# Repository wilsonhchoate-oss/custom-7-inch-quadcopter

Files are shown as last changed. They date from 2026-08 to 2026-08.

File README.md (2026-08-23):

# Custom 7-Inch Quadcopter

> A custom drone I designed, built, and got flying—learning CAD, 3D printing, electronics, and flight control along the way.

<p align="center">
  Completed Custom 7-Inch Quadcopter
</p>

<p align="center">
  <b>Mechanical Design</b> · <b>Additive Manufacturing</b> · <b>Electronics Integration</b> · <b>Flight Controls</b> · <b>Testing & Troubleshooting</b>
</p>

## Flight Demonstration

The custom quadcopter successfully achieved takeoff, stable hover, and controlled flight after iterative mechanical and software refinement.

<p align="center">
  <a href="https://youtube.com/shorts/He_OBPB06JE" target="_blank">
    Flight test video
  </a>
</p>

**[Watch the flight test →](https://youtube.com/shorts/He_OBPB06JE)** This demonstrates stable hover and controlled flight. Full test details in [Testing and Validation](docs/TESTING.md).

## Project Overview

I wanted to learn everything end-to-end. So instead of buying a kit, I designed the frame in Fusion 360, printed it in PETG, integrated all the electronics and motors, and got it flying. It's been a really fun way to learn about how all these systems actually work—from CAD design to 3D printing to flight control.

### Final Result

- **Flight status:** Successful takeoff, hover, and controlled flight
- **Final mass:** Approximately **756 g**
- **Configuration:** Custom X-configuration quadcopter
- **Propellers:** 7-inch, two-blade
- **Battery:** 3S 2200 mAh LiPo
- **Flight software:** Betaflight 4.5.3
- **Airframe material:** PETG
- **CAD platform:** Autodesk Fusion 360

## Why I Built It

Honestly, I just wanted to build a drone and understand how everything works. I wanted to learn how all the parts—motors, controllers, propellers, radio—actually work together as a system. And yeah, I wanted to actually fly something I built myself. Beyond that, I also wanted to create a custom frame that I could iterate on and improve over time. Every drone project teaches me something new, and I can take those lessons and build better versions. That's what excites me about engineering—the continuous improvement cycle and the hands-on learning that comes with it.

## Engineering Development Process

```text
Requirements
      ↓
Component Selection
      ↓
CAD Design (Fusion 360)
      ↓
3D Printing (PETG)
      ↓
Mechanical Assembly
      ↓
Electronics Integration
      ↓
Betaflight Configuration
      ↓
Subsystem Testing
      ↓
Flight Testing
      ↓
Successful Hover
```

## Engineering Highlights

### Mechanical Design

- Designed a modular frame with replaceable arms and separate top and bottom plates.
- Sized the center structure around the flight-controller and ESC stack.
- Incorporated motor mounting, wire routing, fastener access, and structural thickness constraints.
- Used PETG to balance impact resistance, printability, mass, and cost.
- Iterated arm and plate geometry to improve fit, stiffness, and assembly.

### Electronics Integration

- Integrated a 4-in-1 ESC and F405 flight controller.
- Connected A2212 1000KV brushless motors.
- Wired and configured a FlySky receiver using iBUS.
- Used an OVONIC 3S 2200 mAh LiPo battery.
- Resoldered and insulated connections after identifying reliability concerns.
- Verified motor order and direction before installing propellers.

### Flight Controls & Configuration

- Configured Betaflight 4.5.3.
- Calibrated the accelerometer on a level surface.
- Corrected flight-controller orientation and verified the 3D model response.
- Configured receiver endpoints, channel mapping, and an arm switch.
- Verified commanded motor direction against the Betaflight motor diagram.
- Diagnosed apparent throttle increases as flight-controller stabilization response during restrained or unstable testing.

### Testing & Troubleshooting

The project included several failures before successful flight. These failures became the most valuable engineering portion of the build.

| Issue | Investigation | Resolution / Lesson |
|---|---|---|
| Vehicle flipped during takeoff | Checked motor order, motor direction, propeller orientation, board alignment, and accelerometer calibration | Corrected configuration and verified every propulsion channel individually |
| Betaflight model moved incorrectly | Compared physical roll, pitch, and yaw motion with the setup model | Adjusted board orientation and recalibrated |
| Receiver setup problems | Checked wiring, protocol, channel mapping, and endpoints | Used iBUS wiring and configured usable channel ranges |
| Motor speed appeared to increase without throttle input | Evaluated behavior with props removed and during attitude disturbances | Recognized stabilization behavior and avoided unsafe restrained testing with props |
| Suspected unreliable electrical joints | Inspected, resoldered, and insulated connections | Improved electrical reliability and assembly quality |
| Initial flight instability and drift | Rechecked calibration and practiced small control inputs | Achieved flight; future work includes tuning and pilot practice |

## System Specifications

| Subsystem | Component / Value |
|---|---|
| Flight controller | F405-based controller |
| Firmware | Betaflight 4.5.3 |
| ESC | 45 A 4-in-1 ESC |
| Motors | A2212 1000KV brushless outrunners |
| Propellers | 7-inch two-blade |
| Battery | OVONIC 3S, 2200 mAh, 25C |
| Radio transmitter | FlySky FS-i6 |
| Receiver | FlySky receiver using iBUS |
| Frame | Custom Fusion 360 design |
| Frame material | PETG |
| Final vehicle mass | ~756 g |

## Repository Navigation

```text
custom-7-inch-quadcopter/
├── README.md                  # Project overview and recruiter-facing summary
├── docs/
│   ├── DESIGN.md              # Requirements, CAD decisions, and manufacturing
│   ├── ELECTRONICS.md         # Wiring and component integration
│   ├── TESTING.md             # Test plan, failures, and flight validation
│   └── LESSONS_LEARNED.md     # Engineering reflection
├── media/
│   ├── images/                # Build, CAD, wiring, and flight photos
│   └── videos/                # Hover and flight clips
├── cad/                       # CAD renders, drawings, and exported STEP/STL files
├── config/                    # Betaflight backup and settings notes
├── test-data/                 # Mass, motor, battery, or flight-test records
├── BOM.csv                    # Bill of materials
└── .gitignore
```

## Design Process

<p align="center">
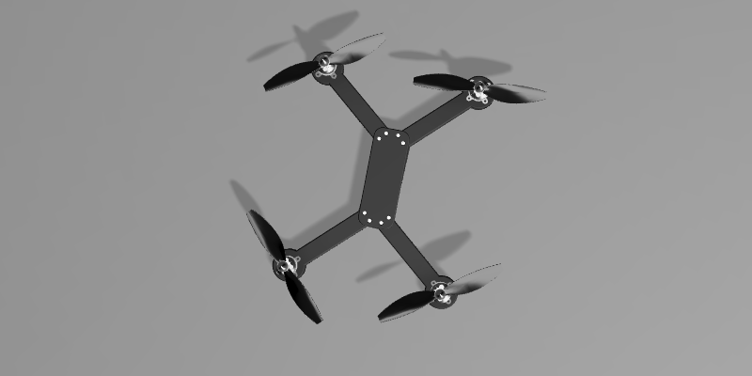
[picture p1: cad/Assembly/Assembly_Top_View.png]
Fusion 360 quadcopter assembly
  
</p>

The airframe was developed around the physical size of the electronics stack, motors, propellers, wiring, and fasteners. The frame uses a central plate assembly and four removable arms. This architecture makes damaged arms replaceable without requiring the entire frame to be reprinted.

More detail: **[Mechanical Design](docs/DESIGN.md)**

## CAD Assembly

The quadcopter was designed as a modular assembly consisting of replaceable motor arms, a two-piece center plate, and commercially available propulsion and control components.

<p align="center">
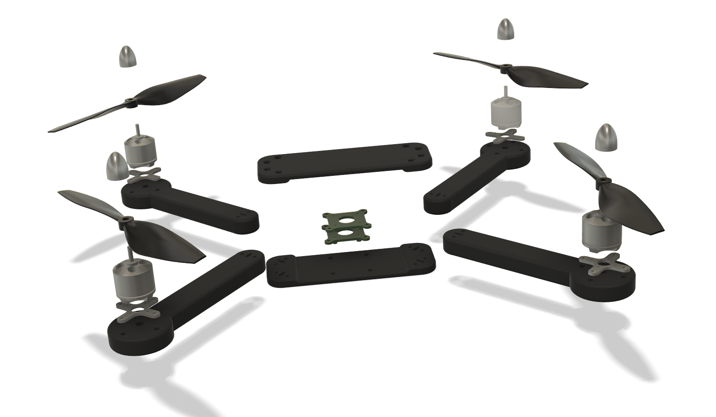
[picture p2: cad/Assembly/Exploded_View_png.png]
Exploded CAD assembly view
  
</p>

The exploded assembly illustrates how the custom manufactured components integrate with the electronics and propulsion system.

## Engineering Documentation

<p align="center">
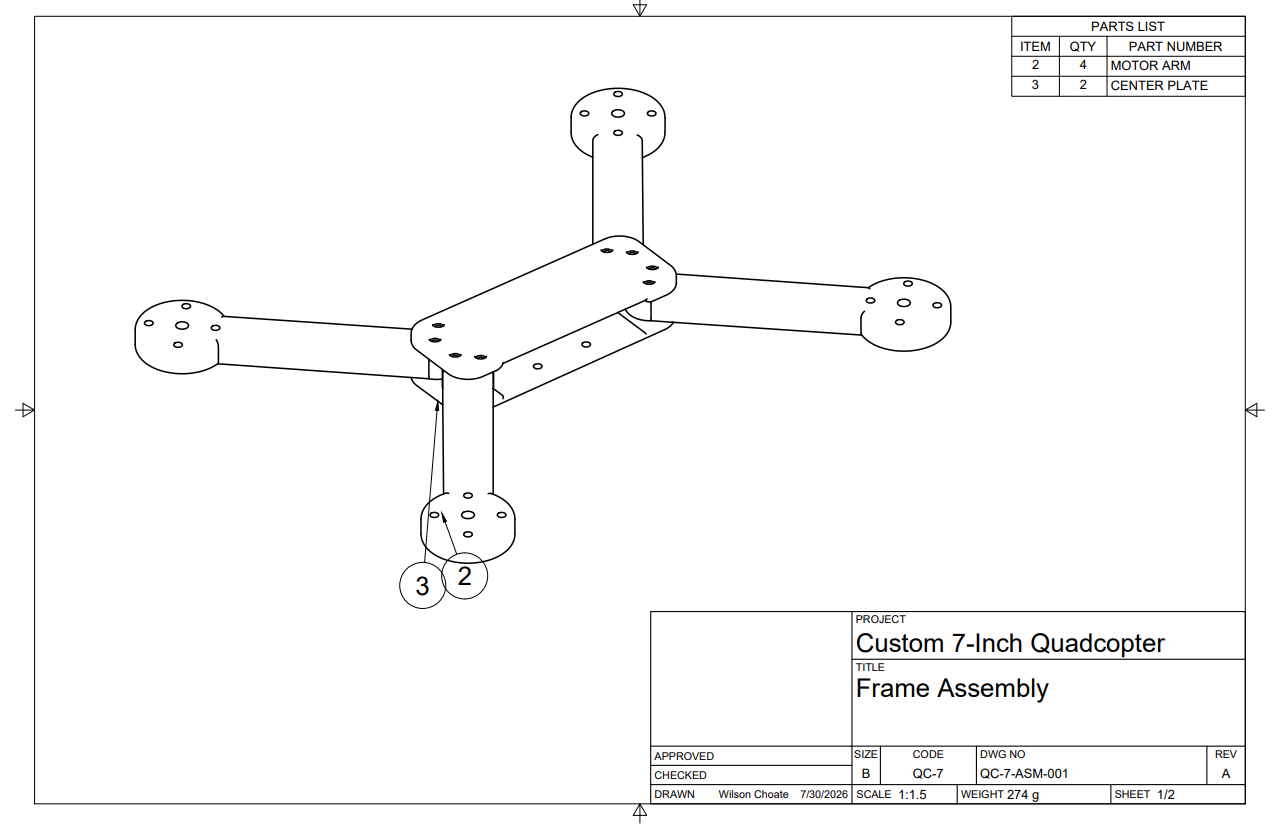
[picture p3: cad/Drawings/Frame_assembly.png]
Engineering drawing of frame assembly

</p>

Professional engineering drawings were created directly from the Fusion 360 assembly including dimensions, exploded views, bill of materials, and assembly references.

## Assembly & Wiring

Assembly required careful management of motor-wire routing, solder-joint quality, receiver connections, component orientation, and access to the flight-controller USB port.

**Assembly details:**
- [electronics-wiring-detail.jpg](media/images/electronics-wiring-detail.jpg) — Flight controller, ESC, receiver, and battery integration
- [flight-controller-mount.jpg](media/images/flight-controller-mount.jpg) — Receiver and FC mounting
- [arm-motor-detail.jpg](media/images/arm-motor-detail.jpg) — Motor, propeller, and power connector

More detail: **[Electronics Integration](docs/ELECTRONICS.md)**

## Validation

The vehicle was tested incrementally rather than proceeding directly to full flight:

- CAD fit and assembly checks
- Continuity and solder-joint inspection
- Smoke-stopper power-up
- Receiver input verification
- Individual motor tests with propellers removed
- Motor order and direction verification
- Accelerometer and orientation verification
- Low-altitude takeoff tests
- Hover and controlled-flight demonstration

More detail: **[Testing and Validation](docs/TESTING.md)**

## Lessons Learned

This project emphasized the importance of validating each subsystem independently before full system integration.

Some of the most valuable lessons included:

- Mechanical design must consider manufacturing and assembly simultaneously.
- Flight controller orientation is critical for stable flight.
- Propeller orientation and motor direction should always be verified independently.
- Careful soldering and wire management improve long-term reliability.
- Incremental testing dramatically reduces troubleshooting time.
- Engineering documentation is just as important as the finished hardware.

## Skills Demonstrated

- Fusion 360 CAD and mechanical design
- Design for additive manufacturing
- PETG 3D printing
- Brushless motor and ESC integration
- Soldering and wiring
- Flight-controller configuration
- Radio and receiver setup
- System-level troubleshooting
- Test planning and risk reduction
- Engineering documentation
- Iterative design and root-cause analysis

## Current Limitations

- The vehicle still requires tuning for smoother low-altitude flight.
- Pilot control proficiency is developing.
- Flight time, vibration, and thrust data have not yet been formally measured.
- Structural performance has not yet been validated with FEA or physical load testing.
- Aerodynamic performance has not yet been evaluated using CFD.

Being explicit about limitations is important: this repository documents a functional prototype, not a production-qualified aircraft.

## Future Work

- Record stabilized hover and forward-flight videos.
- Measure flight time and battery voltage under load.
- Log vibration and gyro data.
- Tune PID and rate settings for low-altitude stability.
- Perform static thrust testing.
- Conduct structural FEA on the arms and center plates.
- Run a basic CFD study around the frame and propeller slipstream.
- Reduce airframe mass while maintaining stiffness.
- Add GPS and autonomous-flight capability using INAV or ArduPilot.

## Safety

Propellers were removed during configuration and motor-direction testing. Initial power-up used a smoke stopper, and flight testing was performed at low altitude in an open area.

## Author

**Wilson Henry Choate**  
Aerospace Engineering Student, Penn State University

- Email: [wilson.choate.pro@gmail.com](mailto:wilson.choate.pro@gmail.com)
- LinkedIn: [linkedin.com/in/wilson-choate-252b5232a](https://www.linkedin.com/in/wilson-choate-252b5232a/)
- GitHub: [github.com/wilsonhchoate-oss](https://github.com/wilsonhchoate-oss)

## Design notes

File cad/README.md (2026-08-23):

# CAD Files

Recommended exports:

- `quadcopter-assembly.step`
- `arm.stl`
- `top-plate.stl`
- `bottom-plate.stl`

Also include 2D drawings or a dimensioned PDF when available.

Do not rely only on the native Fusion 360 file. STEP and STL exports make the project accessible to reviewers using other software.

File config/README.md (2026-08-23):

# Configuration Files

Add the final Betaflight CLI backup here:

- `betaflight-diff-all.txt`

Also add screenshots of key setup pages to `media/images/` when they clarify board alignment, receiver setup, motor order, or flight modes.

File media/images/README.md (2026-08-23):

# Image Checklist

Recommended filenames:

- `hero-hover.jpg` — strongest completed-flight image
- `final-top.jpg`
- `final-side.jpg`
- `final-bottom.jpg`
- `cad-assembly.png`
- `cad-arm-detail.png`
- `electronics-stack.jpg`
- `receiver-wiring.jpg`
- `motor-test.jpg`
- `first-prototype.jpg`
- `failed-revision.jpg`

Use good lighting, a plain background, and landscape orientation when possible.
Do not upload 20 nearly identical images. Keep only images that explain the engineering story.

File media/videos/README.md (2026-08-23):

# Video Checklist

Add:

- `hover-test.mp4` — 10–20 seconds, stable side view
- `takeoff-landing.mp4` — takeoff, brief controlled flight, and landing

Keep clips short. GitHub is not ideal for large video files. Compress them before uploading or place a thumbnail in the README linking to YouTube or another hosted video.

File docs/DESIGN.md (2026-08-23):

# Mechanical Design

## Requirements

The frame needed to:

- Support four A2212 motors and 7-inch propellers.
- Package the flight controller, 4-in-1 ESC, receiver, and battery.
- Be printable on a consumer FDM printer.
- Survive minor low-altitude impacts.
- Allow damaged arms to be replaced.
- Provide access for wiring, fasteners, and the flight-controller USB port.
- Keep total vehicle mass low enough for stable flight.

## Architecture

The selected architecture uses four removable arms captured between top and bottom center plates. This modular approach reduces repair cost and print time after an impact.

## Material Selection

PETG was selected because it provides greater toughness and heat resistance than standard PLA while remaining easy to print on a consumer machine.

## Design Decisions to Document With Images

Add annotated screenshots for:

1. Overall frame dimensions.
2. Arm cross-section and motor mount.
3. Center plate and electronics-stack mounting.
4. Fastener and nut-trap geometry.
5. Arm-to-center-plate interface.
6. Final Fusion 360 assembly.
7. Slicer orientation and print settings.

## Manufacturing

Record the final settings used:

| Parameter | Final Value |
|---|---|
| Printer | Bambu Lab A1 |
| Material | PETG |
| Nozzle diameter | Not yet recorded |
| Layer height | Not yet recorded |
| Wall loops | Not yet recorded |
| Top layers | Not yet recorded |
| Bottom layers | Not yet recorded |
| Infill percentage | Not yet recorded |
| Infill pattern | Not yet recorded |
| Nozzle temperature | Not yet recorded |
| Bed temperature | Not yet recorded |
| Total frame print mass | Not yet recorded |

## Design Evolution

Include 2–4 images showing how the design changed. For each revision, explain:

- What was wrong with the prior version.
- What changed.
- Why the change improved the design.
- Whether the change affected mass, stiffness, print time, or assembly.

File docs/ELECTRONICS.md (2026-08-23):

# Electronics Integration

## System Architecture

```text
3S LiPo
   |
   v
4-in-1 ESC ------> Four brushless motors
   |
   v
Flight Controller
   |
   +------> FlySky receiver via iBUS
   |
   +------> USB connection for Betaflight
```

## Wiring Documentation

Add a clear wiring diagram and close-up photographs. Label:

- Battery positive and ground
- ESC-to-flight-controller connection
- Motor outputs 1–4
- Receiver 5 V, ground, and iBUS signal
- Flight-controller orientation arrow
- USB access direction

## Configuration Summary

| Setting | Value |
|---|---|
| Firmware | Betaflight 4.5.3 |
| Receiver protocol | iBUS |
| Arm control | AUX switch |
| Motor protocol | Not yet recorded |
| Board alignment | Not yet recorded |
| Channel map | Not yet recorded |
| Failsafe behavior | Not yet recorded |

## Quality Checks

- Inspected solder joints.
- Verified polarity before power-up.
- Used a smoke stopper during initial power testing.
- Tested receiver channels in Betaflight.
- Tested each motor individually without propellers.
- Confirmed motor direction and motor numbering.
- Secured and insulated wiring before flight.

## Betaflight Backup

Export the final configuration using the Betaflight CLI:

```text
diff all
```

Save the output as:

```text
config/betaflight-diff-all.txt
```

Do not publish Wi-Fi passwords, personal information, serial numbers you consider private, or unrelated device data.

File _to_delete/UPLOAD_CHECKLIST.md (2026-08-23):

# GitHub Upload Checklist

## Before publishing

- [ ] Replace every `ADD` placeholder.
- [ ] Add a strong hover image as `media/images/hero-hover.jpg`.
- [ ] Add completed top, side, and bottom photos.
- [ ] Add Fusion 360 screenshots.
- [ ] Add at least one wiring image.
- [ ] Add one failed or early revision image.
- [ ] Add the short hover video.
- [ ] Export STEP and STL files.
- [ ] Export the final Betaflight `diff all`.
- [ ] Fill in the bill of materials and approximate cost.
- [ ] Fill in the flight-test log.
- [ ] Add LinkedIn, GitHub, and professional email.
- [ ] Proofread every page.
- [ ] Confirm no private data appears in screenshots or configuration files.

## GitHub repository settings

Suggested repository name:

`custom-7-inch-quadcopter`

Suggested description:

`Custom PETG quadcopter designed in Fusion 360, integrated with an F405 flight controller, and validated through low-altitude flight testing.`

Suggested topics:

`quadcopter`, `drone`, `uav`, `aerospace-engineering`, `fusion-360`, `betaflight`, `3d-printing`, `petg`, `flight-controls`, `embedded-systems`

Pin this repository on your GitHub profile after publishing it.

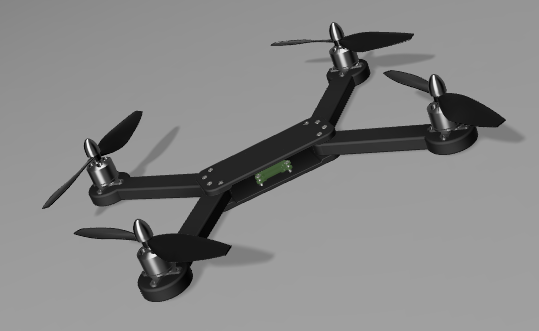
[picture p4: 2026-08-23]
media/images/hero-render.png

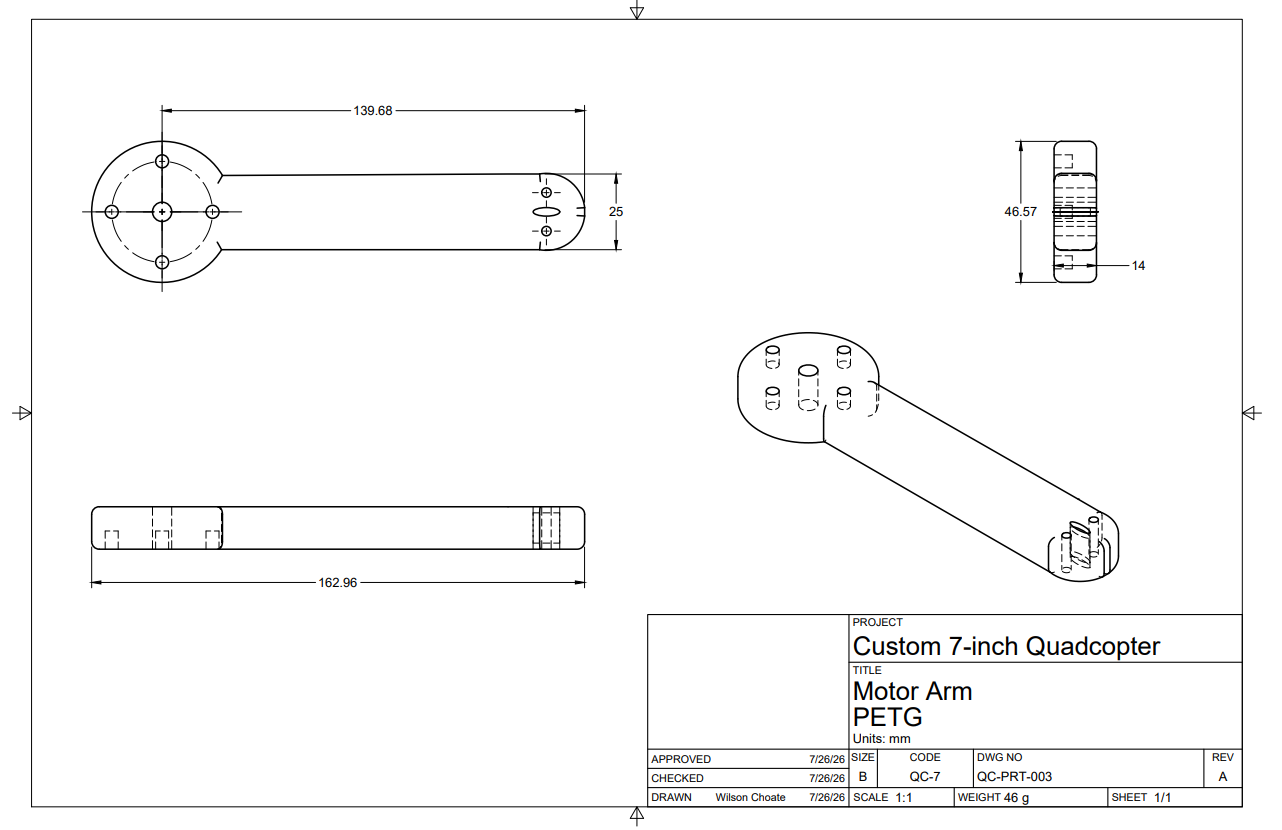
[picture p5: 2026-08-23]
cad/Drawings/Motor_arm_drawing.png

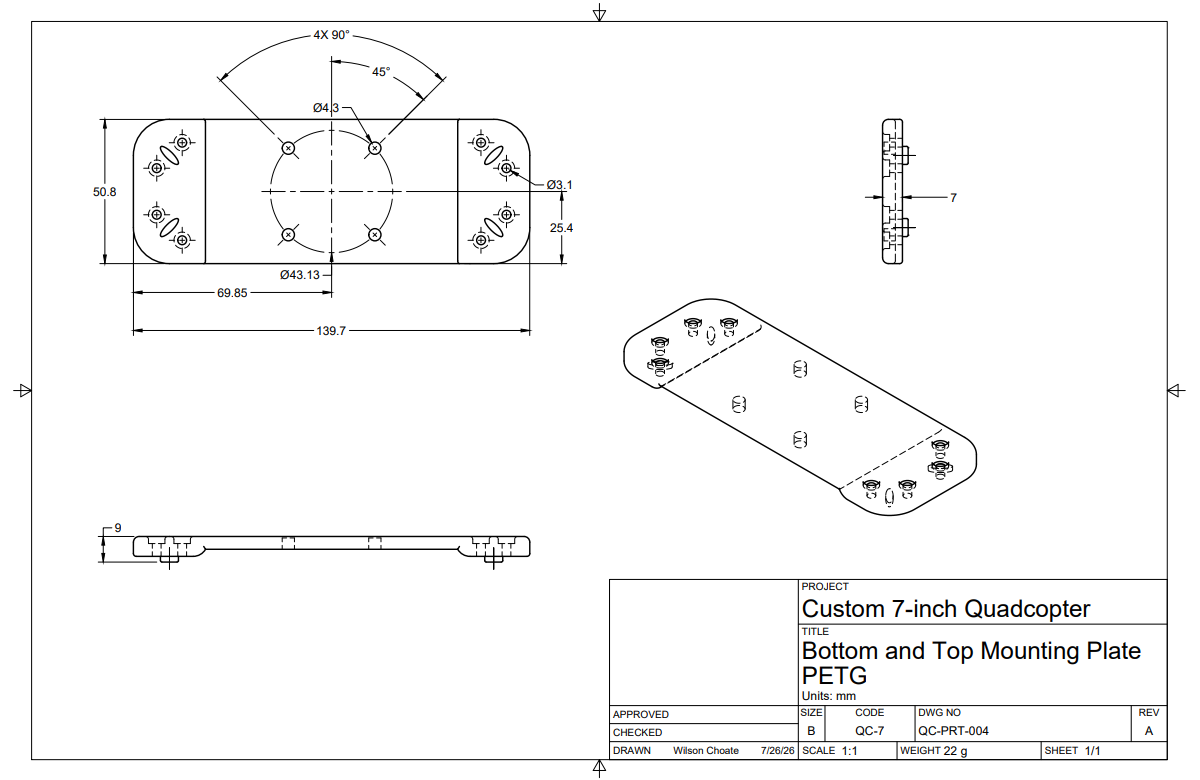
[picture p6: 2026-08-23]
cad/Drawings/Center_plate_drawing.png

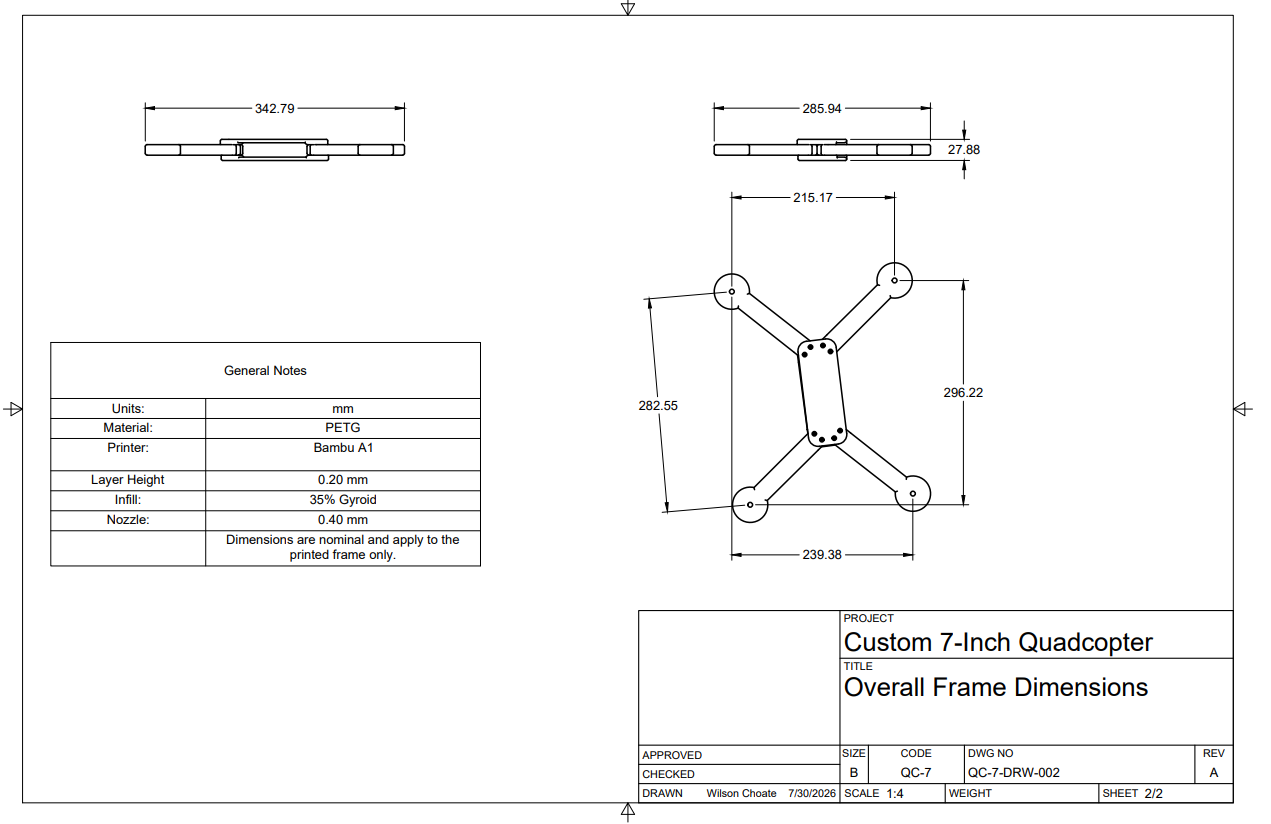
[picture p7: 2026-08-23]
cad/Drawings/Overall_frame_dimensions.png

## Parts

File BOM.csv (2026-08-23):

Category | Component | Specification | Quantity | Cost_USD | Source_URL | Notes
Flight Control | Flight controller | F405-based, Betaflight 4.5.3 | 1 | 30 | Amazon/AliExpress | Omnibus F4 or equivalent
Power Electronics | 4-in-1 ESC | 45 A | 1 | 45 | HobbyKing/Amazon | Integrated with flight controller support
Propulsion | Brushless motor | A2212 1000KV | 4 | 48 | Amazon/HobbyKing | ~$12 per motor (qty 4)
Propulsion | Propeller | 7-inch two-blade | 1 set (4 total) | 12 | Amazon | 2x CW + 2x CCW orientation
Power | LiPo battery | 3S 2200 mAh 25C | 1 | 28 | Amazon | Sufficient for ~2.5 min hover time
Radio | Transmitter | FlySky FS-i6 | 1 | 60 | Amazon | Standard 6-channel transmitter
Radio | Receiver | FlySky, iBUS | 1 | 18 | Amazon | iBUS compatible with flight controller
Structure | Printed frame | Custom PETG | 1 | 5 | Prusament/Prusament | ~250g filament at typical material cost
Hardware | Fasteners | M3 bolts, connectors, wire | 1 set | 25 | Amazon | M3 bolts; XT60 connectors; 16 AWG silicone wire
Other | Smoke stopper / safety | Pre-flight testing equipment | 1 | 15 | Amazon | Inline fuse or current-limiting power supply
Total |  |  | Qty: 16 items | 286 |  | $30+$45+$48+$12+$28+$60+$18+$5+$25+$15

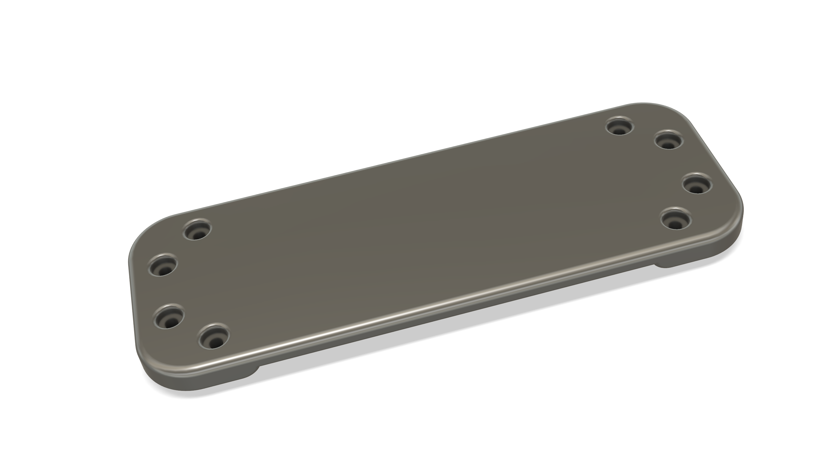
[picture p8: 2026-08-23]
cad/Component_Designs/Center Plate Bottom View.png

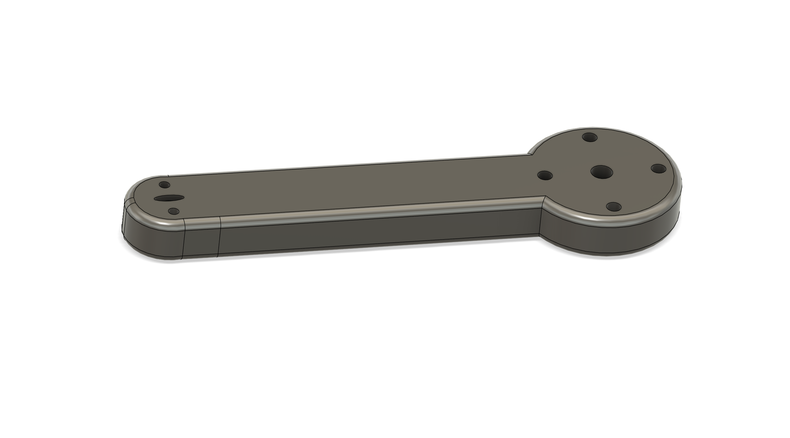
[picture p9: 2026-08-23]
cad/Component_Designs/Motor Arm.png

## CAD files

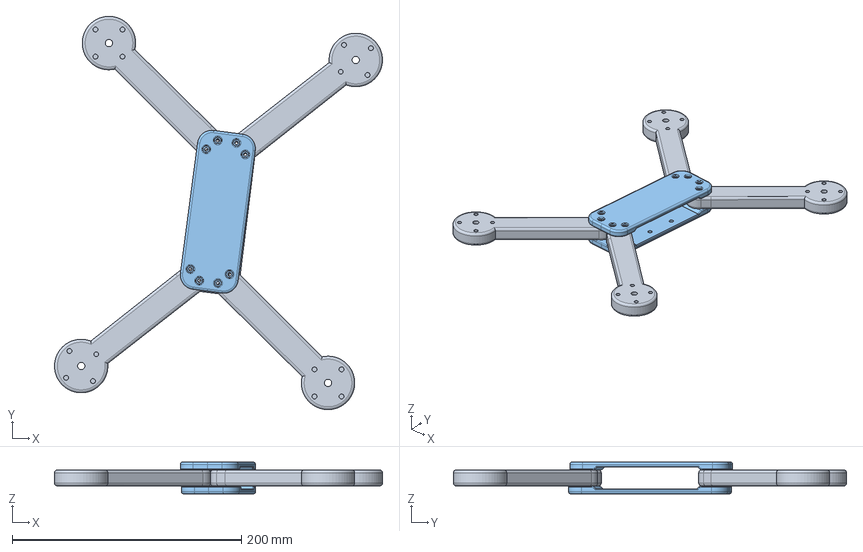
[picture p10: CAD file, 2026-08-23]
cad/assembly.step
285.9 x 342.8 x 27.9 mm
QUADCOPTER 2.0 (v10~recovered) x 4
bottom plate (v8~recovered) x 2
Motor Mount (4)
Motor Mount (1)
ESC
Motor (1)
Motor (2)
Motor (4)
Motor (3)
Propellers
Flight Controller
Motor Mount (3)
Motor Mount (2)
Prop+7x4х2.stl
Prop+7x4х2.stl (1)
Prop+7x4х2.stl (1) (1)
Prop_Top_M5 (1) (1) (1)
Prop_Top_M5 (1) (1)
Prop_Top_M5 (1)
Prop_Top_M5

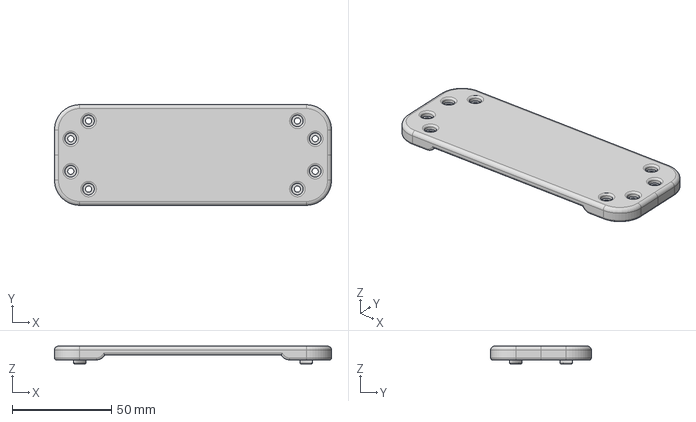
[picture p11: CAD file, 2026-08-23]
cad/Center_Plate.step
139.7 x 50.8 x 9.00 mm

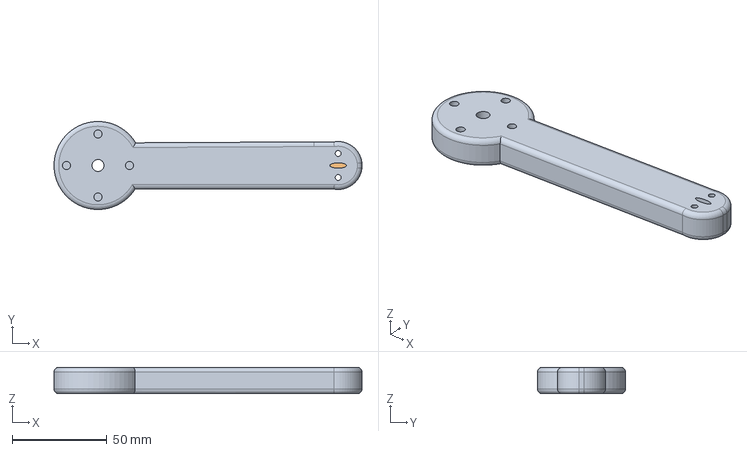
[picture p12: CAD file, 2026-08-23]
cad/Motor_Arm.step
163.0 x 46.5 x 14.0 mm

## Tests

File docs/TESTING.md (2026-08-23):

# Testing and Validation

## Test Philosophy

Testing progressed from low-risk subsystem checks to integrated flight tests. Propellers were not installed until receiver input, flight-controller orientation, motor order, and motor direction had been verified.

## Test Matrix

| Test | Configuration | Pass Criteria | Result |
|---|---|---|---|
| Visual inspection | Unpowered | No exposed conductors or loose hardware | PASS |
| Continuity / polarity | Unpowered | No short across battery input | Not recorded |
| Smoke-stopper power-up | Props removed | Normal startup, no overheating | PASS |
| Receiver test | Props removed | Correct channel response and endpoints | PASS |
| Accelerometer test | Props removed | Betaflight model matches physical motion | PASS |
| Individual motor test | Props removed | Correct motor responds | PASS |
| Direction test | Props removed | Each motor matches diagram | PASS |
| One-minute motor run | Props removed | No abnormal heating or vibration | PASS |
| Low-throttle test | Props installed | Symmetric spool-up | PASS |
| Takeoff test | Open area | Clean liftoff without tip-over | PASS AFTER ITERATION |
| Hover test | Low altitude | Sustained controlled hover | PASS |
| Controlled flight | Open area | Pilot can translate and land safely | PASS |

## Failure Analysis

### Takeoff Flip

**Observed behavior:** The aircraft became light on its landing surface and flipped.

**Possible causes evaluated:**

- Incorrect motor order
- Incorrect motor rotation
- Incorrect propeller placement
- Incorrect flight-controller orientation
- Incorrect accelerometer calibration
- Uneven or unstable launch surface
- Wiring or ESC output problem

**Corrective process:**

1. Removed propellers.
2. Verified each motor number in Betaflight.
3. Verified each motor's physical rotation.
4. Matched propellers to the required rotation.
5. Checked the setup model against physical roll, pitch, and yaw movement.
6. Recalibrated the accelerometer on a level surface.
7. Retested on a flat, rigid surface.

**Outcome:** Successful flight was achieved after configuration and assembly checks.

## Flight Evidence to Add

Capture:

- 10–20 second stationary hover from the side.
- Takeoff, short translation, and landing.
- Close-up image of the completed vehicle.
- Top, bottom, and side views.
- One image with the battery installed.
- One image showing the controller and aircraft together.

## Quantitative Data to Add

- Takeoff mass
- Hover throttle
- Hover time
- Battery voltage before and after flight
- Motor temperature after flight
- Maximum stable altitude tested
- Propeller size
- Ambient wind conditions

Store raw measurements in `test-data/`.

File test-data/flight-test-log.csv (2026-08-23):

Date | Configuration | Mass_g | Propeller | Battery_Start_V | Battery_End_V | Hover_Throttle | Flight_Time_s | Wind | Result | Notes
Not yet recorded | Initial successful flight | 756 | 7-inch two-blade |  |  |  |  |  | PASS | Detailed measurements to be logged on next test session

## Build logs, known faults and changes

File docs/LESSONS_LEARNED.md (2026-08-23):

# Lessons Learned

## 1. System integration is harder than component selection

Every component can work individually while the aircraft still fails as a system. Motor numbering, rotation, propeller orientation, board alignment, radio setup, wiring, and calibration all must agree.

## 2. A failure is useful only when the test isolates variables

Repeatedly attempting takeoff without changing one controlled variable provides little information. Removing propellers and checking motor order, direction, orientation, and receiver response individually made troubleshooting more effective.

## 3. Flight-controller behavior can look like a hardware problem

The controller changes motor outputs to correct attitude error. During restrained or unstable testing, this can sound like uncontrolled throttle increase even though the controller is responding as programmed.

## 4. Mechanical accessibility matters

USB access, solder-pad access, wire routing, fastener clearance, and replaceable parts should be considered during CAD—not after printing.

## 5. Documentation should happen during the build

Photographs of failed revisions, wiring changes, and test setups are more valuable than only showing the finished aircraft. They demonstrate engineering judgment and iteration.

## 6. Successful flight is not the end of the project

A functional prototype creates opportunities for better testing: vibration logging, PID tuning, static thrust measurement, structural analysis, CFD, mass optimization, and autonomous flight.
